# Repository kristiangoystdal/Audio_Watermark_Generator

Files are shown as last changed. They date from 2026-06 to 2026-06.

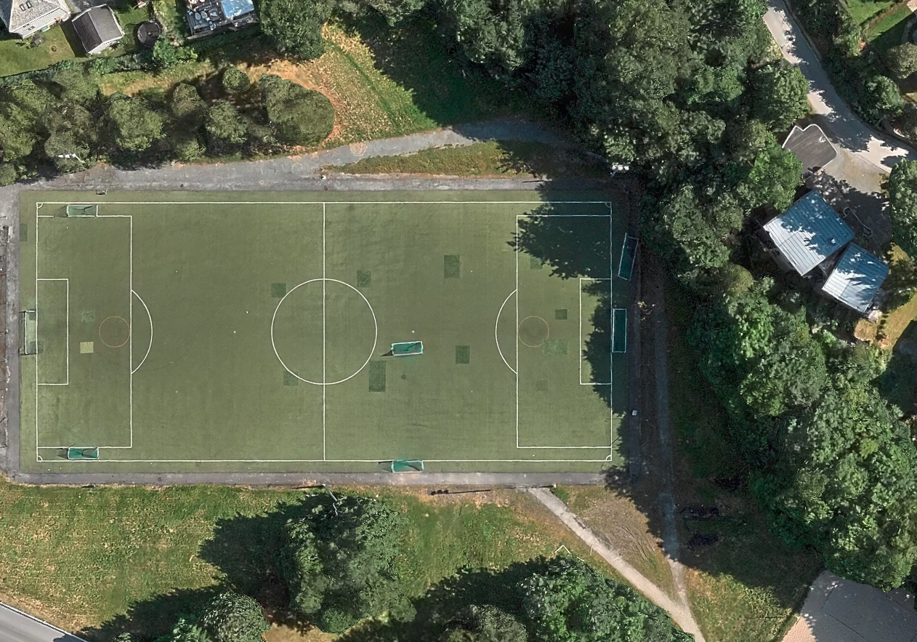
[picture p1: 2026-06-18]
Testing/test_files/acoustic_localization/dødens_dal_2/SATELLITE_IMAGE.png

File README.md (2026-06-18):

# Acoustic Metadata Multiplexer

A low-cost, low-power system for embedding time-synchronized FSK metadata signals into audio recordings made by Autonomous Recording Units (ARUs). Designed for bioacoustic field deployments where cross-unit time synchronization and metadata recovery from audio alone are required.

The system encodes a structured metadata payload as a BFSK signal mixed into the audio recorded by any ARU model — either acoustically via a speaker, or electrically via a 3.5 mm cabled pass-through. A desktop demodulator extracts the metadata from recorded `.wav` files post-deployment.

---

## How It Works

The system operates in a **star topology**: one unit acts as a base station and the others are receivers, one per ARU.

1. **Base station** wakes on a fixed schedule, generates a common payload (message ID, timestamp, user string), and broadcasts it over RF at 433 MHz using the CC1101 transceiver.
2. **Receiver units** listen on the CC1101 in continuous RX mode. On receiving a packet, each receiver generates a BFSK-modulated audio signal encoding the shared payload combined with its own local data (device ID, GPS coordinates, live temperature from DS3231).
3. The FSK signal is mixed into the audio captured by the ARU — either by playing it through a small speaker near the ARU microphone, or by mixing it into a microphone signal over a cabled 3.5 mm connection.
4. Since all receivers embed at the same time (triggered by the same RF packet), the embedded signal appears at the same absolute moment across all ARU recordings — enabling post-hoc time alignment via the message ID.
5. A recorded `.wav` containing the embedded signal can be decoded using the desktop demodulator to recover both the metadata and the synchronization reference point.

**Standalone mode** skips RF communication entirely: the unit generates and embeds its own payload on a fixed schedule, using only locally configured and measured data.

The metadata payload format is:

```
/MID<id>/TIM<timestamp>/STR<string>/DID<device_id>/LOC<lat,lon>/TMP<temperature>/
```

Each field is optional and individually togglable via `user_config.h` or the GUI. `MID` (message ID) is the synchronization anchor — recordings are aligned by matching identical message IDs across units.

---

## Repository Structure

```
Audio_Watermark_Generator/
├── Firmware/                   # STM32G431 embedded firmware
│   ├── Core/
│   │   ├── Inc/                # Headers (drivers, config, DSP)
│   │   └── Src/                # Source (main loop, peripherals, FEC)
│   ├── Drivers/                # HAL, CMSIS, and DSP libraries
│   ├── Middlewares/            # USB device library
│   ├── USB_Device/             # USB CDC interface
│   ├── cmake/                  # CMake toolchain config
│   ├── CMakeLists.txt
│   └── CMakePresets.json
│
├── Hardware/                   # KiCad PCB design
│   ├── *.kicad_sch             # Schematics (MCU, RTC, mixer, speaker, transceiver, battery)
│   ├── *.kicad_pcb             # PCB layout
│   ├── Components/             # Custom footprints, symbols, and 3D models
│   ├── Gerber/                 # Fabrication files
│   └── JCLPCB/                 # BOM and CPL for JLCPCB assembly
│
├── Software/                   # Desktop tools (Python)
│   ├── gui/                    # Configurator and flash tool
│   │   ├── gui.py              # Main GUI application
│   │   ├── build_app.py        # PyInstaller build script
│   │   ├── scripts/            # Config generation, build automation, paths
│   │   └── tools/              # Bundled toolchain (ARM GCC, CMake, Ninja, dfu-util)
│   │
│   └── gui_demodulator/        # Metadata decoder
│       ├── demodulator_gui.py  # Decoder GUI
│       ├── demodulator.py      # FSK demodulation engine
│       └── reed_solomon.py     # Reed-Solomon decoder
│
├── Testing/                    # Test scripts and data
│   ├── scripts/                # Individual test scripts
│   │   └── helper/             # Shared utilities
│   ├── test_files/             # Input audio and measurement data
│   ├── results/                # Output plots and reports
│   └── run_all_tests.py        # Run all tests
│
└── README.md
```

---

## Getting Started

### Prerequisites

| Component | Requirement |
| --- | --- |
| Microcontroller | STM32G431-based board (custom PCB or Nucleo) |
| Toolchain | GNU Arm Embedded Toolchain 13.2+ |
| Build system | CMake + Ninja |
| Programmer | ST-Link V3 or DFU over USB |
| Python | 3.8+ with `tkinter` |

### Install Python Dependencies

```bash
pip install numpy scipy matplotlib soundfile
```

> `tkinter` is included with most Python installations. On Linux, you may need `sudo apt install python3-tk`.

---

## Firmware

### Key Configuration

All metadata and system parameters are defined in [`Firmware/Core/Inc/user_config.h`](Firmware/Core/Inc/user_config.h):

| Parameter | Default | Description |
| --- | --- | --- |
| `USER_STRING` | `"Hello World"` | User-defined string payload |
| `DEVICE_ID` | `42` | Numeric identifier for this unit |
| `LOCATION` | `"63.4190,10.4015"` | GPS coordinates of this ARU |
| `TEMPERATURE` | `20` | Static temperature fallback (overridden by DS3231 reading at runtime) |
| `INCLUDE_USER_STRING` / `INCLUDE_DEVICE_ID` / etc. | `true` | Toggle individual payload fields on/off |
| `FSK_LOWER_FREQUENCY` | `10000` Hz | FSK f0 tone (auto-aligned to DAC sample rate) |
| `FSK_HIGHER_FREQUENCY` | `12000` Hz | FSK f1 tone (auto-aligned to DAC sample rate) |
| `SIGNAL_ATTENUATION` | `100` | Output level (0 = silence, 100 = full) |
| `USE_REED_SOLOMON_ERROR_CORRECTION` | `true` | Enable/disable RS error correction |
| `RS_ERROR_CORRECTION_SYMBOLS` | `20` | Number of RS parity symbols |
| `OPERATION_MODE` | `0` | 0 = Receiver, 1 = Base Station, 2 = Standalone |
| `STARTING_HOUR` / `END_HOUR` | `0` / `23` | Daily schedule window (24h format) |
| `RUN_MINUTES` / `SLEEP_MINUTES` | `3` / `0` | Duty cycle within the schedule window |
| `USE_CABLE_TRANSMISSION` | `false` | Cable (3.5 mm) output instead of speaker |

You can edit this file manually or use the GUI configurator (see below).

### Operation Modes

**Receiver (`OPERATION_MODE=0`)**
Listens on the CC1101 in continuous RX mode. On receiving a packet, the unit generates a metadata string combining shared fields from the RF packet (message ID, timestamp, user string) with its own local fields (device ID, location, temperature), then outputs the BFSK signal. One receiver unit is deployed at each ARU.

**Base Station (`OPERATION_MODE=1`)**
Wakes on a fixed RTC-based schedule, generates a common payload (message ID, RTC timestamp, user string), and transmits it via the CC1101 RF transceiver. One unit per deployment must be configured as the base station.

**Standalone (`OPERATION_MODE=2`)**
No RF communication. The unit wakes on a fixed RTC-based schedule, generates a payload from locally configured and measured values, and outputs the BFSK signal. Used when cross-unit synchronization is not needed.

### Features

- **BFSK metadata embedding** — DMA-driven circular DAC output with pre-computed sine LUTs; frequencies are auto-aligned to integer samples-per-period for zero spectral leakage
- **Reed-Solomon FEC** — GF(2^8) encoder with configurable parity symbols for burst-error-resilient decoding
- **CC1101 sub-GHz RF** — bit-banged SPI driver for 433 MHz base station to receiver synchronization; receiver uses continuous RX mode
- **DS3231 RTC** — I2C temperature-compensated clock with battery backup; software-controlled power gating to save current between reads
- **Scheduled operation** — configurable active hours (`STARTING_HOUR`/`END_HOUR`) and run/sleep duty cycle aligned to AudioMoth duty-cycle timing; RTC wakeup timer for Base Station/Standalone, GPIO interrupt (GDO0) for Receiver (mode 0)
- **Audio output paths** — speaker (GPIO-switched amplifier) or cable (relay-switched gain-neutral mixing mode with op-amp signal chain)
- **Battery monitoring** — ADC reading through a resistor divider; halts with error code if voltage drops below 3.0 V
- **USB CDC** — serial interface for host communication and first-boot RTC time sync
- **Flash-persistent flags** — records whether time sync has been performed (survives power cycles)
- **LED status codes** — 4-bit binary blink patterns encoding error/status codes, repeated 3 times
- **STOP1 low-power mode** — full peripheral suspend between transmissions; clock and I2C re-initialized on wake

### Build

```bash
cd Firmware
cmake -B build/Debug -S . -G Ninja -DCMAKE_BUILD_TYPE=Debug
cmake --build build/Debug
```

### Flash

**Via ST-Link:**

```bash
openocd -f interface/stlink.cfg -f target/stm32g4x.cfg \
  -c "program build/Debug/Audio_Watermark_Generator.elf verify reset exit"
```

**Via DFU (USB):**
The GUI flash tool handles DFU flashing automatically. Alternatively, use `dfu-util` directly.

---

## Software Tools

### Configurator & Flash Tool

A desktop GUI for configuring metadata parameters and flashing the firmware to the STM32.

```bash
cd Software/gui
python3 gui.py
```

**What it does:**

- Configure metadata fields per operation mode (base station, receiver, standalone)
- Set FSK frequencies, attenuation, and Reed-Solomon error correction
- Set operation schedule (active hours, run/sleep intervals)
- Generate `user_config.h`, build the firmware, and flash over DFU

The tool bundles its own ARM toolchain, CMake, Ninja, and dfu-util in `Software/gui/tools/`, so no manual toolchain setup is needed when using the GUI.

### Metadata Decoder

A desktop GUI for extracting embedded metadata from recorded audio files.

```bash
cd Software/gui_demodulator
python3 demodulator_gui.py
```

**What it does:**

- Load a `.wav` recording containing an embedded BFSK signal
- Perform FSK demodulation and Reed-Solomon decoding
- Display the decoded metadata payload
- Visualize the demodulated spectrum and signal

### Pre-built macOS Apps

Beta `.app` builds are available for macOS:

- **Audio Watermark Flash Tool** — configure and flash
- **FSK Audio Demodulator** — decode metadata from recordings

[Download the latest release](../../releases/latest)

---

## Testing

The `Testing/` directory contains scripts for characterizing and validating system performance.

### Test Scripts

| Script | Description |
| --- | --- |
| `autotest.py` | Automated demodulator correctness testing |
| `drift.py` | Frequency drift measurement over time |
| `ecc_burst_test.py` | Reed-Solomon burst error correction validation |
| `offset_calculation.py` | Timing offset between devices |
| `localize.py` | Acoustic localization from multi-receiver recordings |
| `localize_tdoa.py` | Time-difference-of-arrival (TDOA) localization |
| `audio_passthrough.py` | Audio signal chain validation (FFT analysis) |
| `spec_leak.py` | Spectral purity and leakage analysis |
| `timing.py` | Transmission timing validation |
| `wakeup.py` | Sleep/wakeup mechanism testing |
| `plot_fsk_signals.py` | FSK signal visualization |
| `plot_bird_spectrograms.py` | Spectrogram analysis of bird audio |
| `plot_current.py` | Current consumption analysis |
| `plot_rssi.py` | RF signal strength plotting |
| `plot_temperature.py` | Temperature variation analysis |

### Test Data

Test input data is organized in `Testing/test_files/`:

- `demodulator_autotest/` — Pre-recorded samples for demodulator validation
- `acoustic_localization/` — Multi-receiver recordings for TDOA testing
- `rtc_measurements/` — RTC drift data
- `range_tests/` — Distance-dependent RF signal quality
- `current_measures/` — Power consumption logs
- `temperature_range/` — Temperature sweep recordings

### Run All Tests

```bash
cd Testing
python3 run_all_tests.py
```

---

## Hardware

The custom 4-layer PCB is designed in KiCad and includes:

- **STM32G431** microcontroller
- **DS3231** RTC with battery backup
- **CC1101** RF transceiver (433 MHz, sub-GHz)
- Audio mixer with gain-neutral pass-through and speaker driver
- USB connector
- Battery power management

Design files are in `Hardware/`:

- Schematics: individual `.kicad_sch` files for each subsystem
- PCB layout: `Audio_watermark_generator.kicad_pcb`
- 3D model: `Audio_watermark_generator.step`
- Fabrication: `Gerber/` directory with Gerber + drill files
- Assembly: `JCLPCB/` with BOM and CPL for JLCPCB ordering
- Custom components: `Components/` with footprints, symbols, and 3D models

---

## Contributing

1. Fork the repository
2. Create a feature branch (`git checkout -b feature/my-feature`)
3. Commit your changes
4. Push and open a pull request

---

## Contributors

- **Kristian Gøystdal** — Developer
- **Einar Bergslid** — Developer

---

## License

Released under the **MIT License**. Free to use, modify, and distribute.

---

`stm32` · `bioacoustics` · `autonomous-recording-unit` · `time-synchronization` · `fsk` · `metadata-embedding` · `reed-solomon` · `kicad` · `python`

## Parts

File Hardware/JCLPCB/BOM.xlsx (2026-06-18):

Reference | Qty | Value | DNP | Footprint | LCSC Part #
 |  |  | DNP
C1 | 1 | 4u7F |  | Capacitor_SMD:C_0603_1608Metric | C19666
C2,C3,C9,C20,C51 | 5 | 100nF |  | Capacitor_SMD:C_0402_1005Metric | C1525
C4,C21,C22 | 3 | 10nF |  | Capacitor_SMD:C_0402_1005Metric | C15195
C5,C6,C15 | 3 | 1uF |  | Capacitor_SMD:C_0603_1608Metric | C15849
C7,C8 | 2 | 10pF |  | Capacitor_SMD:C_0402_1005Metric | C32949
C10,C11 | 2 | 22uF |  | Capacitor_SMD:C_0805_2012Metric | C45783
C12,C16 | 2 | 10uF |  | Capacitor_SMD:C_0805_2012Metric | C440198
C13,C14 | 2 | 4n7F |  | Capacitor_SMD:C_0603_1608Metric | C53987
C17,C18,C23,C24,C25,C124,C125 | 7 | 220pF |  | Capacitor_SMD:C_0402_1005Metric | C71693
C19 | 1 | 1uF |  | Capacitor_SMD:C_0805_2012Metric | C77079
C26,C27,C28 | 3 | 22uF |  | Capacitor_SMD:C_0603_1608Metric | C84419
C81 | 1 | 12pF |  | Capacitor_SMD:C_0402_1005Metric | C1547
C101 | 1 | 15pF |  | Capacitor_SMD:C_0402_1005Metric | C1548
C121,C131 | 2 | 3p9F |  | Capacitor_SMD:C_0402_1005Metric | C85940
C122 | 1 | 8p2F |  | Capacitor_SMD:C_0402_1005Metric | C76984
C123 | 1 | 5p6F |  | Capacitor_SMD:C_0402_1005Metric | C85941
D1 | 1 | RED |  | LED_SMD:LED_0603_1608Metric | C2286
FB1 | 1 | 120R |  | Inductor_SMD:L_0603_1608Metric | C14709
FB2,FB3 | 2 | 600R |  | Inductor_SMD:L_0603_1608Metric | C1002
FB4 | 1 | 1kR |  | Inductor_SMD:L_0402_1005Metric | C76889
IC1 | 1 | STM32G431KBT6 (https://www.digikey.com/en/products/detail/stmicroelectronics/STM32G431KBT6/10231564) |  | QFP80P900X900X160-32N | C529357
IC2 | 1 | ISL91107IRTNZ-T7A (https://no.rs-online.com/web/p/voltage-regulators/1230989) |  | QFN50P300X400X80-21N | C2071659
J1 | 1 | USB_B_Micro (https://no.rs-online.com/web/p/usb-connectors/1225099) |  | USB_Micro-B_Wuerth_629105150521 | C2894326
 |  |  | DNP
 |  |  | DNP
J4,J5 | 2 | SJ2-35954A-SMT-TR |  | CUI_SJ2-35954A-SMT-TR | C4992345
J6 | 1 | 533980271_Picoblade (https://no.rs-online.com/web/p/pcb-headers/6563024) |  | MOLEX_533980271_Picoblade | C122410
 |  |  | DNP
 |  |  | DNP
K1 | 1 | AGQ210S03 (https://www.digikey.no/no/products/detail/panasonic-electric-works/AGQ210S03/644869) |  | AGQ210S03 | C5582831
L1 | 1 | 1uH |  | Inductor_SMD:L_1008_2520Metric | C470857
L121,L123,L131 | 3 | 27nH |  | Inductor_SMD:L_0402_1005Metric | C12669
L122 | 1 | 22nH |  | Inductor_SMD:L_0402_1005Metric | C12670
R1 | 1 | 1k5R |  | Resistor_SMD:R_0402_1005Metric | C25867
R2 | 1 | 10kR |  | Resistor_SMD:R_0402_1005Metric | C25744
R3,R4,R5,R6 | 4 | 100kR |  | Resistor_SMD:R_0805_2012Metric | C25611
R7 | 1 | 2kR |  | Resistor_SMD:R_0805_2012Metric | C17604
R8,R9 | 2 | 10kR |  | Resistor_SMD:R_0805_2012Metric | C17414
R10,R12 | 2 | 1kR |  | Resistor_SMD:R_0805_2012Metric | C17513
R11 | 1 | 1MR |  | Resistor_SMD:R_0805_2012Metric | C17514
R13,R14 | 2 | 330kR |  | Resistor_SMD:R_0805_2012Metric | C17629
R171 | 1 | 56kR |  | Resistor_SMD:R_0402_1005Metric | C71703
SW2,SW1 | 2 | SW_SPDT (https://no.rs-online.com/web/p/slide-switches/7931721) |  | SW_SPDT_PCM12 | C221841
U1 | 1 | AMS1117-3.3 (https://www.digikey.no/no/products/detail/umw/AMS1117-3-3/17635254) |  | Package_TO_SOT_SMD:SOT-223-3_TabPin2 | C6186
U2 | 1 | L9110S |  | Driver:SOIC127P599X172-8N | C725793
U3,U4 | 2 | MCP6072 (https://www.digikey.no/no/products/detail/microchip-technology/MCP6072-E-SN/2059969) |  | OpAmp:SOIC127P599X175-8N | C122875
U5 | 1 | PAM8304 (https://no.farnell.com/diodes-inc/pam8304asr/audio-power-amp-d-40-to-85deg/dp/3373822) |  | Audio_Module:PAM8304ASR | C581342
 |  |  | DNP
U8 | 1 | CC1101 (https://no.rs-online.com/web/p/rf-ics/8203068) |  | RF_Module:CC1101 | C29953
Y1 | 1 | 16MHz (https://no.rs-online.com/web/p/crystal-units/2365070) |  | Crystal:Crystal_SMD_3225-4Pin_3.2x2.5mm | C112972
Y2 | 1 | 26Mhz (https://no.rs-online.com/web/p/crystal-units/2365070) |  | Crystal:Crystal_SMD_3225-4Pin_3.2x2.5mm | C485372

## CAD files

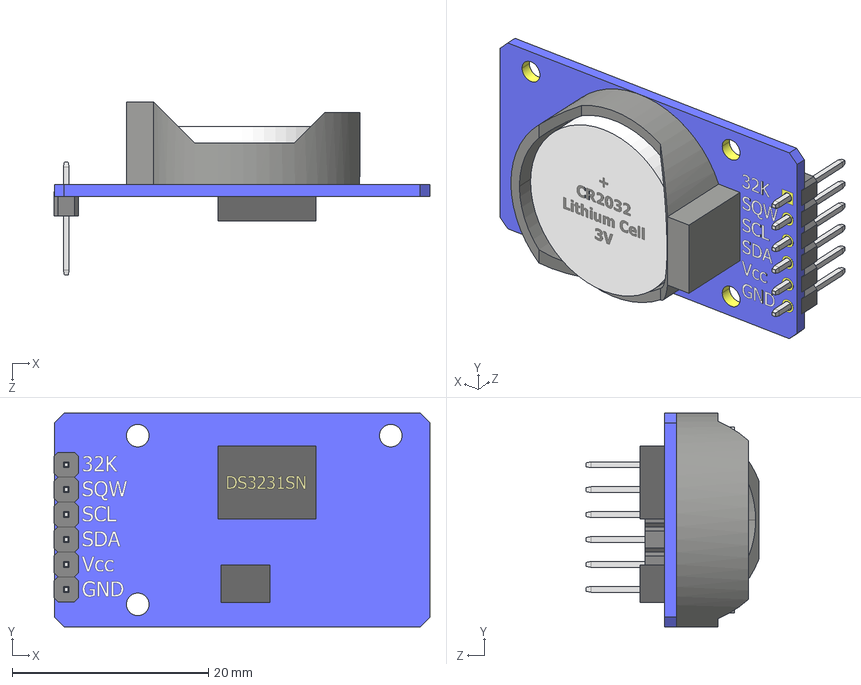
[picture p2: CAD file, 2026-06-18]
Hardware/Components/Models/DS3231 Timer Assembly.STEP
38.3 x 21.8 x 17.6 mm
PCB Timer
Battery Holder
ICs
HEADER10P

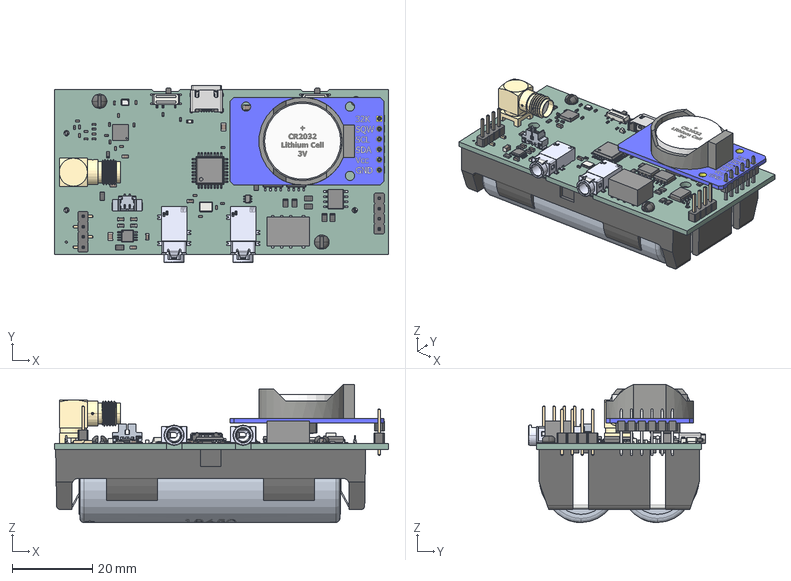
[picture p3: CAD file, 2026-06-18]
Hardware/Audio_watermark_generator.step
83.0 x 44.1 x 34.3 mm
C_0402_1005Metric x 21
PinHeader_1x04_P2.54mm_Vertical_SMD_Pin1Right
ThermalPin
PinsArrayLR x 3
PinsArrayTB x 2
C_0805_2012Metric x 7
C_0603_1608Metric x 9
PCB Timer
Battery Holder
ICs
HEADER10P
Crystal_SMD_3225-4Pin_3.2x2.5mm
L_0603_1608Metric x 3
CC1101
logo
dot
pins
R_0805_2012Metric x 16
CONSMA002-SMD-G-T
L_0402_1005Metric x 4
LED_0603_1608Metric
MCP6072-E_SN x 3
R_0603_1608Metric
SJ2-35954A-SMT-TR--3DModel-STEP-1 x 2
R_0402_1005Metric x 2
PAM8304ASR
629105150521_Housing
629105150521_Pin1 x 4
629105150521_Pin2
629105150521_Shielding2
629105150521_Shielding
L_1210_3225Metric
PinHeader_1x04_P2.54mm_Vertical
Pins
SOT-223
SW_SPDT_PCM12 x 2
keystone-PN1049
Audio_watermark_generator_PCB

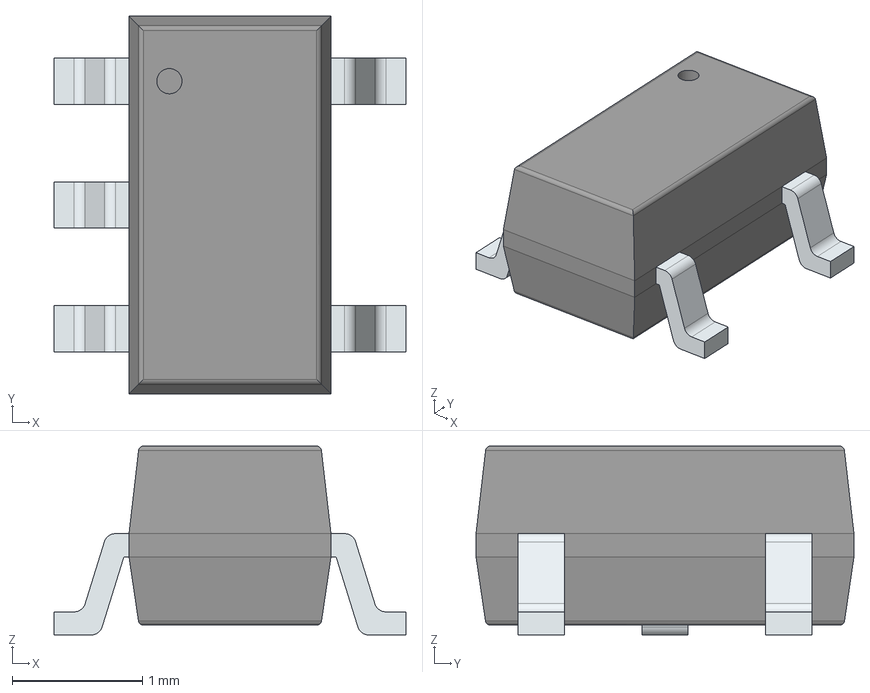
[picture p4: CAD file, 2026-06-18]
Hardware/Components/Models/MCP6071T-E_OT.stp
2.70 x 2.90 x 1.45 mm
PinsArrayL
PinsArrayR

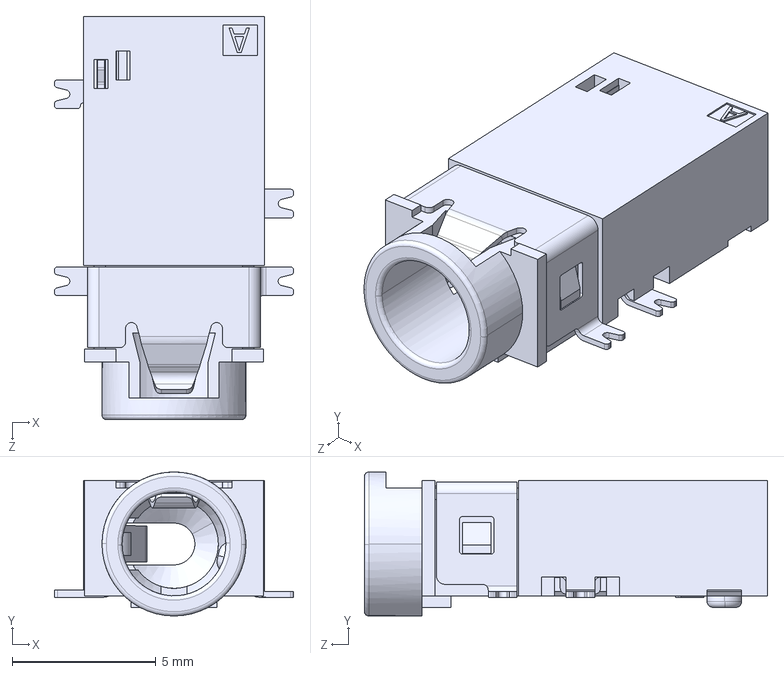
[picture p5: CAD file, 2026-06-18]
Hardware/Components/Models/SJ2-35954A-SMT-TR--3DModel-STEP-1.STEP
8.30 x 5.00 x 14.0 mm

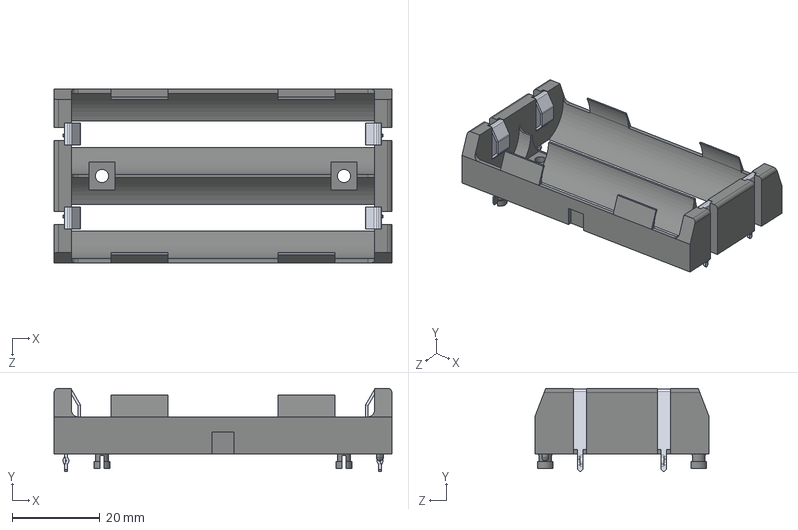
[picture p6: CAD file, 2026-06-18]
Hardware/Components/Models/1049.stp
77.1 x 19.0 x 39.8 mm

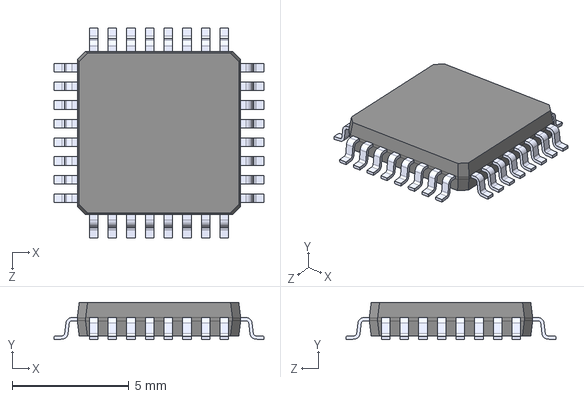
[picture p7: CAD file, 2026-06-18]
Hardware/Components/Models/STM32G431KBT6.STEP
9.00 x 1.60 x 9.00 mm

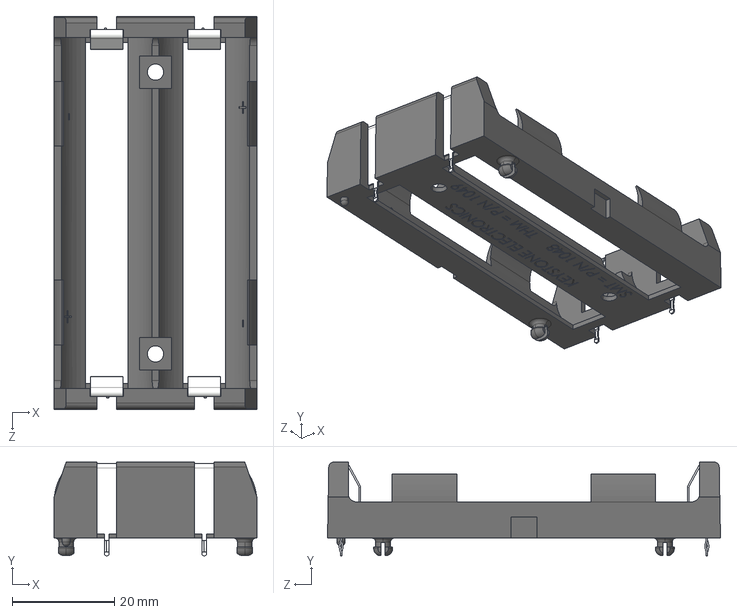
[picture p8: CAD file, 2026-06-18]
Hardware/Components/Models/keystone-PN1049.STEP
39.8 x 18.4 x 77.1 mm

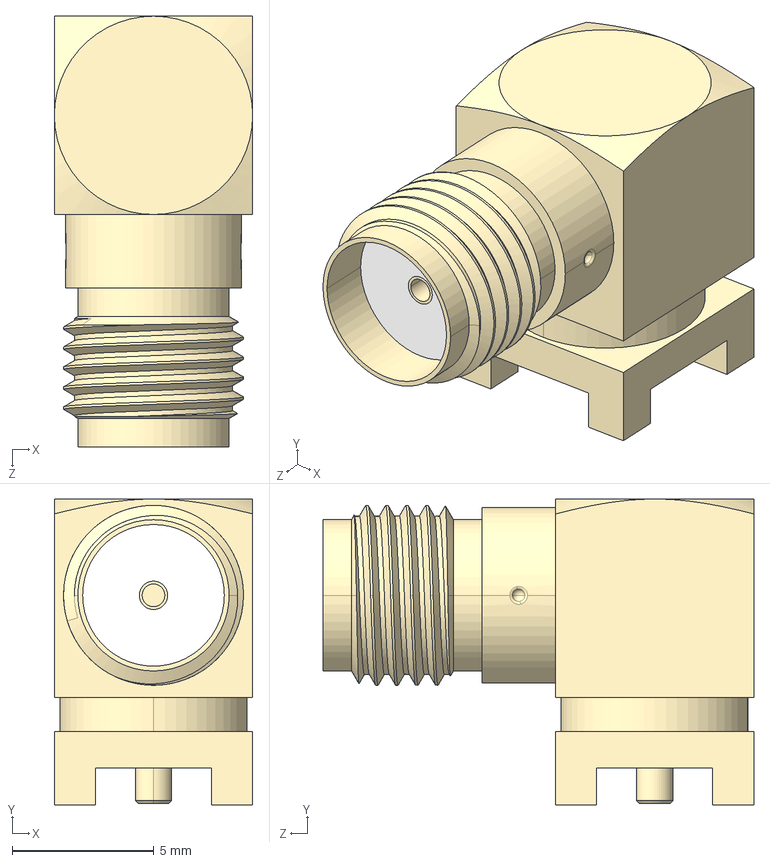
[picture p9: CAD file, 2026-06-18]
Hardware/Components/Models/CONSMA002-SMD-G-T.step
7.00 x 10.8 x 15.2 mm

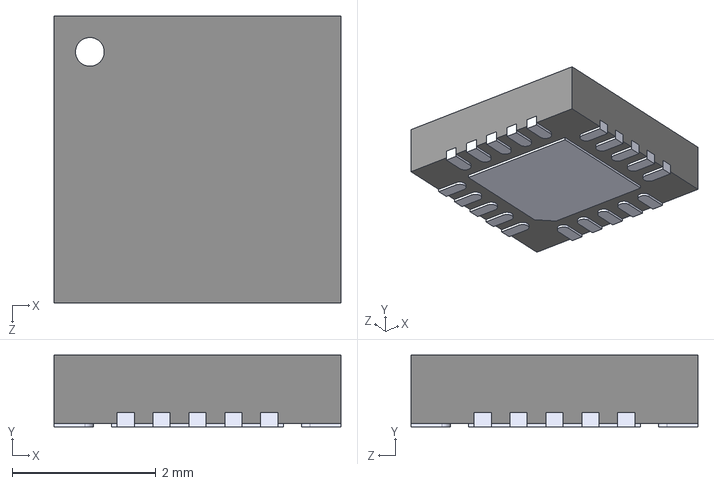
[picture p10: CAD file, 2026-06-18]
Hardware/Components/Models/CC1101.step
4.00 x 1.00 x 4.00 mm

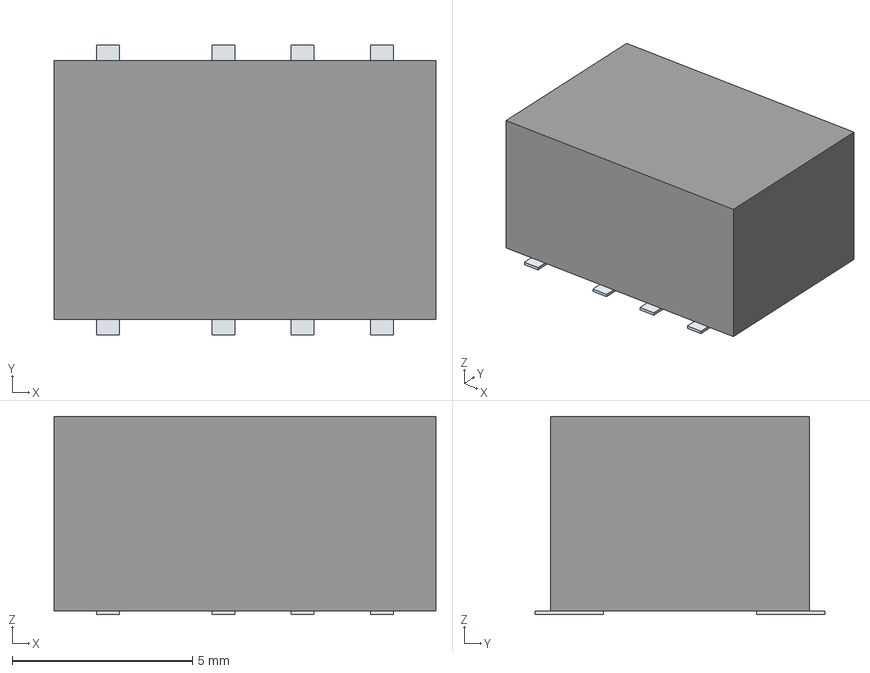
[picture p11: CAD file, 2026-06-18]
Hardware/Components/Models/AGQ210S03.stp
10.6 x 8.04 x 5.50 mm
Pins

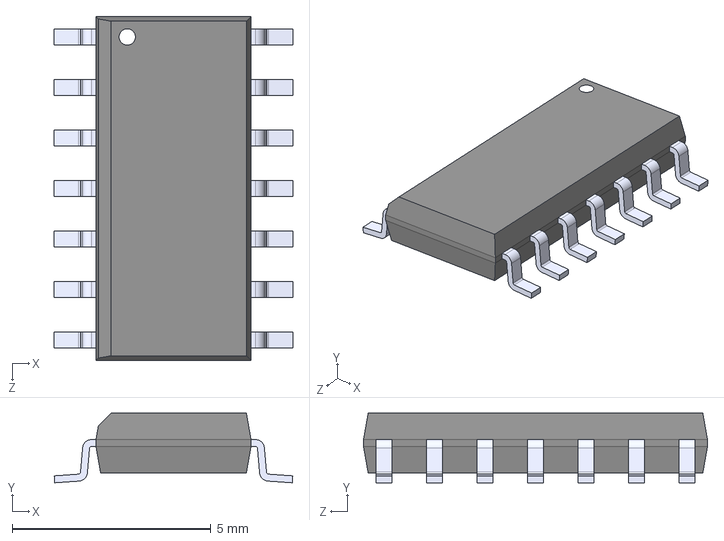
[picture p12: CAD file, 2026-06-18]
Hardware/Components/Models/MCP6004-I_SL.STEP
6.00 x 1.75 x 8.65 mm

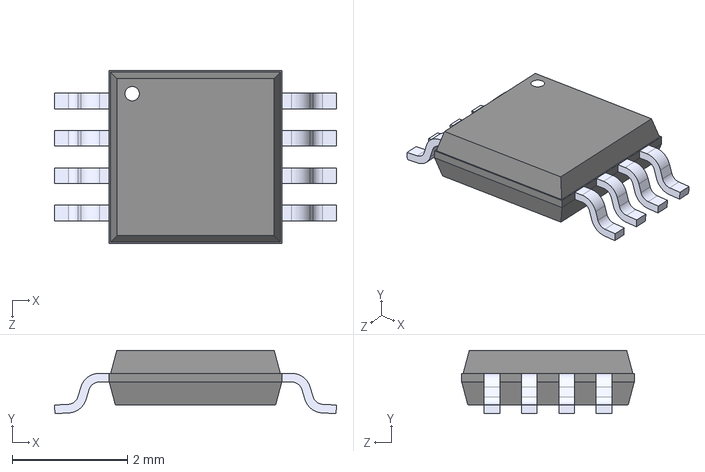
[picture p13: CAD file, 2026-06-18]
Hardware/Components/Models/PAM8304ASR.step
4.90 x 1.10 x 3.00 mm

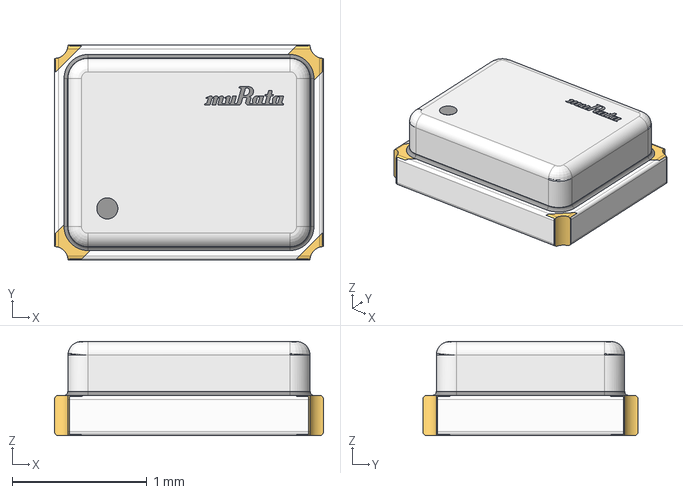
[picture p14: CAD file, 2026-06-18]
Hardware/Components/Models/XRCGB26M000F1S1DR0.stp
2.00 x 1.60 x 0.702 mm

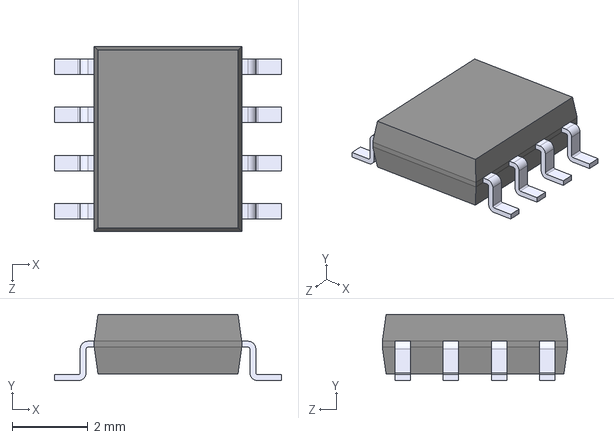
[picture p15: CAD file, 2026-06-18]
Hardware/Components/Models/MCP6072-E_SN.step
6.00 x 1.75 x 4.90 mm

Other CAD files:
Hardware/Components/Models/AGQ200S03Z.stp
Hardware/Components/Models/STG3157CTR.stp
Hardware/Components/Models/L9110S--3DModel-STEP-269445.STEP
Hardware/Components/Models/18650.STEP
Hardware/Components/Models/533980271.step
Hardware/Components/Models/629105150521+%28rev1%29.stp
Hardware/Components/Models/ISL91107IRTNZ-T7A.stp
Hardware/Components/Models/MCP6004-I_P.STEP

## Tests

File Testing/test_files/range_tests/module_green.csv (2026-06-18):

Distance (m) | Module | RX Data | RSSI (dBm)
5 | green | *ë/MID00/STRHello World/TIM1211500522052026 | -57
5 | green | *ë/MID00/STRHello World/TIM1211560522052026 | -56
5 | green | *ë/MID00/STRHello World/TIM1212030522052026 | -55
5 | green | *ë/MID00/STRHello World/TIM1212100522052026 | -56
5 | green | *ë/MID00/STRHello World/TIM1212190522052026 | -54
5 | green | *ë/MID00/STRHello World/TIM1212250522052026 | -52
5 | green | *ë/MID00/STRHello World/TIM1212320522052026 | -52
5 | green | *ë/MID00/STRHello World/TIM1212390522052026 | -51
5 | green | *ë/MID00/STRHello World/TIM1212490522052026 | -50
5 | green | *ë/MID00/STRHello World/TIM1212580522052026 | -50
10 | green | *ë/MID00/STRHello World/TIM1226410522052026 | -61
10 | green | *ë/MID00/STRHello World/TIM1226470522052026 | -60
10 | green | *ë/MID00/STRHello World/TIM1226540522052026 | -61
10 | green | *ë/MID00/STRHello World/TIM1227010522052026 | -62
10 | green | *ë/MID00/STRHello World/TIM1227080522052026 | -62
10 | green | *ë/MID00/STRHello World/TIM1227140522052026 | -62
10 | green | *ë/MID00/STRHello World/TIM1227210522052026 | -63
10 | green | *ë/MID00/STRHello World/TIM1227270522052026 | -63
10 | green | *ë/MID00/STRHello World/TIM1227340522052026 | -63
10 | green | *ë/MID00/STRHello World/TIM1227480522052026 | -61
10 | green | *ë/MID00/STRHello World/TIM1227540522052026 | -61
15 | green | *ë/MID00/STRHello World/TIM1229080522052026 | -61
15 | green | *ë/MID00/STRHello World/TIM1229140522052026 | -62
15 | green | *ë/MID00/STRHello World/TIM1229210522052026 | -62
15 | green | *ë/MID00/STRHello World/TIM1229330522052026 | -61
15 | green | *ë/MID00/STRHello World/TIM1229400522052026 | -62
15 | green | *ë/MID00/STRHello World/TIM1229470522052026 | -62
15 | green | *ë/MID00/STRHello World/TIM1229540522052026 | -62
15 | green | *ë/MID00/STRHello World/TIM1230010522052026 | -62
15 | green | *ë/MID00/STRHello World/TIM1230070522052026 | -63
15 | green | *ë/MID00/STRHello World/TIM1230140522052026 | -63
15 | green | *ë/MID00/STRHello World/TIM1230210522052026 | -62
20 | green | *ë/MID00/STRHello World/TIM1231460522052026 | -64
20 | green | *ë/MID00/STRHello World/TIM1231530522052026 | -64
20 | green | *ë/MID00/STRHello World/TIM1232000522052026 | -64
20 | green | *ë/MID00/STRHello World/TIM1232070522052026 | -64
20 | green | *ë/MID00/STRHello World/TIM1232130522052026 | -64
20 | green | *ë/MID00/STRHello World/TIM1232200522052026 | -64
20 | green | *ë/MID00/STRHello World/TIM1232270522052026 | -64
20 | green | *ë/MID00/STRHello World/TIM1232340522052026 | -64
20 | green | *ë/MID00/STRHello World/TIM1232400522052026 | -64
20 | green | *ë/MID00/STRHello World/TIM1232470522052026 | -65
25 | green | *ë/MID00/STRHello World/TIM1233470522052026 | -67
25 | green | *ë/MID00/STRHello World/TIM1233540522052026 | -65
25 | green | *ë/MID00/STRHello World/TIM1234010522052026 | -67
25 | green | *ë/MID00/STRHello World/TIM1234070522052026 | -66
25 | green | *ë/MID00/STRHello World/TIM1234140522052026 | -67
25 | green | *ë/MID00/STRHello World/TIM1234220522052026 | -66
25 | green | *ë/MID00/STRHello World/TIM1234280522052026 | -66
25 | green | *ë/MID00/STRHello World/TIM1234350522052026 | -66
25 | green | *ë/MID00/STRHello World/TIM1234420522052026 | -66
25 | green | *ë/MID00/STRHello World/TIM1234490522052026 | -65
30 | green | *ë/MID00/STRHello World/TIM1235390522052026 | -69
30 | green | *ë/MID00/STRHello World/TIM1235460522052026 | -69
30 | green | *ë/MID00/STRHello World/TIM1235530522052026 | -69
30 | green | *ë/MID00/STRHello World/TIM1236000522052026 | -70
30 | green | *ë/MID00/STRHello World/TIM1236070522052026 | -70
30 | green | *ë/MID00/STRHello World/TIM1236140522052026 | -70
30 | green | *ë/MID00/STRHello World/TIM1236210522052026 | -73
30 | green | *ë/MID00/STRHello World/TIM1236280522052026 | -73
30 | green | *ë/MID00/STRHello World/TIM1236340522052026 | -74
30 | green | *ë/MID00/STRHello World/TIM1236410522052026 | -73
35 | green | *ë/MID00/STRHello World/TIM1237320522052026 | -76
35 | green | *ë/MID00/STRHello World/TIM1237390522052026 | -77
35 | green | *ë/MID00/STRHello World/TIM1237460522052026 | -76
35 | green | *ë/MID00/STRHello World/TIM1237520522052026 | -77
35 | green | *ë/MID00/STRHello World/TIM1237590522052026 | -73
35 | green | *ë/MID00/STRHello World/TIM1238060522052026 | -71
35 | green | *ë/MID00/STRHello World/TIM1238130522052026 | -70
35 | green | *ë/MID00/STRHello World/TIM1238200522052026 | -69
35 | green | *ë/MID00/STRHello World/TIM1238270522052026 | -69
35 | green | *ë/MID00/STRHello World/TIM1238350522052026 | -70
40 | green | *ë/MID00/STRHello World/TIM1239270522052026 | -74
40 | green | *ë/MID00/STRHello World/TIM1239340522052026 | -73
40 | green | *ë/MID00/STRHello World/TIM1239400522052026 | -73
40 | green | *ë/MID00/STRHello World/TIM1239470522052026 | -74
40 | green | *ë/MID00/STRHello World/TIM1239540522052026 | -73
40 | green | *ë/MID00/STRHello World/TIM1240010522052026 | -73
40 | green | *ë/MID00/STRHello World/TIM1240070522052026 | -74
40 | green | *ë/MID00/STRHello World/TIM1240140522052026 | -71
40 | green | *ë/MID00/STRHello World/TIM1240210522052026 | -71
40 | green | *ë/MID00/STRHello World/TIM1240270522052026 | -70
45 | green | *ë/MID00/STRHello World/TIM1312160522052026 | -87
45 | green | *ë/MID01/STRHello World/TIM1312190522052026 | -84
45 | green | *ë/MID02/STRHello World/TIM1312220522052026 | -83
45 | green | *ë/MID03/STRHello World/TIM1312250522052026 | -85
45 | green | *ë/MID04/STRHello World/TIM1312280522052026 | -84
45 | green | *ë/MID05/STRHello World/TIM1312310522052026 | -88
45 | green | *ë/MID06/STRHello World/TIM1312340522052026 | -86
45 | green | *ë/MID07/STRHello World/TIM1312380522052026 | -86
45 | green | *ë/MID08/STRHello World/TIM1312410522052026 | -87
45 | green | *ë/MID09/STRHello World/TIM1312440522052026 | -89
50 | green | *ë/MID00/STRHello World/TIM1313290522052026 | -82
50 | green | *ë/MID01/STRHello World/TIM1313330522052026 | -81
50 | green | *ë/MID02/STRHello World/TIM1313360522052026 | -81
50 | green | *ë/MID03/STRHello World/TIM1313390522052026 | -80
50 | green | *ë/MID04/STRHello World/TIM1313420522052026 | -82
50 | green | *ë/MID05/STRHello World/TIM1313450522052026 | -81
50 | green | *ë/MID06/STRHello World/TIM1313480522052026 | -80
50 | green | *ë/MID07/STRHello World/TIM1313510522052026 | -81
50 | green | *ë/MID08/STRHello World/TIM1313540522052026 | -79
50 | green | *ë/MID09/STRHello World/TIM1313570522052026 | -80
55 | green | *ë/MID00/STRHello World/TIM1314490522052026 | -80
55 | green | *ë/MID01/STRHello World/TIM1314520522052026 | -78
55 | green | *ë/MID02/STRHello World/TIM1314550522052026 | -77
55 | green | *ë/MID03/STRHello World/TIM1314590522052026 | -78
55 | green | *ë/MID04/STRHello World/TIM1315020522052026 | -77
55 | green | *ë/MID05/STRHello World/TIM1315050522052026 | -78
55 | green | *ë/MID06/STRHello World/TIM1315080522052026 | -74
55 | green | *ë/MID07/STRHello World/TIM1315110522052026 | -70
55 | green | *ë/MID08/STRHello World/TIM1315140522052026 | -70
55 | green | *ë/MID09/STRHello World/TIM1315170522052026 | -72
60 | green | *ë/MID00/STRHello World/TIM1316020522052026 | -86
60 | green | *ë/MID01/STRHello World/TIM1316050522052026 | -83
60 | green | *ë/MID02/STRHello World/TIM1316080522052026 | -85
60 | green | *ë/MID03/STRHello World/TIM1316110522052026 | -84
60 | green | *ë/MID04/STRHello World/TIM1316140522052026 | -85
60 | green | *ë/MID05/STRHello World/TIM1316170522052026 | -83
60 | green | *ë/MID06/STRHello World/TIM1316200522052026 | -81
60 | green | *ë/MID07/STRHello World/TIM1316230522052026 | -84
60 | green | *ë/MID08/STRHello World/TIM1316260522052026 | -83
60 | green | *ë/MID09/STRHello World/TIM1316300522052026 | -82
65 | green | *ë/MID01/STRHello World/TIM1317140522052026 | -94
65 | green | *ë/MID02/STRHello World/TIM1317170522052026 | -86
65 | green | *ë/MID03/STRHello World/TIM1317200522052026 | -86
65 | green | *ë/MID04/STRHello World/TIM1317240522052026 | -83
65 | green | *ë/MID05/STRHello World/TIM1317270522052026 | -88
65 | green | *ë/MID06/STRHello World/TIM1317300522052026 | -89
65 | green | *ë/MID07/STRHello World/TIM1317330522052026 | -85
65 | green | *ë/MID08/STRHello World/TIM1317360522052026 | -85
65 | green | *ë/MID09/STRHello World/TIM1317390522052026 | -89
70 | green | *ë/MID00/STRHello World/TIM1318290522052026 | -83
70 | green | *ë/MID01/STRHello World/TIM1318320522052026 | -83
70 | green | *ë/MID02/STRHello World/TIM1318350522052026 | -82
70 | green | *ë/MID03/STRHello World/TIM1318380522052026 | -84
70 | green | *ë/MID04/STRHello World/TIM1318410522052026 | -83
70 | green | *ë/MID05/STRHello World/TIM1318440522052026 | -83
70 | green | *ë/MID06/STRHello World/TIM1318470522052026 | -82
70 | green | *ë/MID07/STRHello World/TIM1318500522052026 | -84
70 | green | *ë/MID08/STRHello World/TIM1318540522052026 | -85
70 | green | *ë/MID09/STRHello World/TIM1318570522052026 | -85
75 | green | *ë/MID00/STRHello World/TIM1334300522052026 | -78
75 | green | *ë/MID01/STRHello World/TIM1334330522052026 | -78
75 | green | *ë/MID02/STRHello World/TIM1334360522052026 | -78
75 | green | *ë/MID03/STRHello World/TIM1334400522052026 | -77
75 | green | *ë/MID04/STRHello World/TIM1334430522052026 | -76
75 | green | *ë/MID05/STRHello World/TIM1334460522052026 | -77
75 | green | *ë/MID06/STRHello World/TIM1334490522052026 | -76
75 | green | *ë/MID07/STRHello World/TIM1334520522052026 | -75
75 | green | *ë/MID08/STRHello World/TIM1334550522052026 | -76
75 | green | *ë/MID09/STRHello World/TIM1334580522052026 | -75
80 | green | *ë/MID01/STRHello World/TIM1335520522052026 | -92
80 | green | *ë/MID03/STRHello World/TIM1335580522052026 | -92
80 | green | *ë/MID04/STRHello World/TIM1336010522052026 | -88
80 | green | *ë/MID05/STRHello World/TIM1336040522052026 | -85
80 | green | *ë/MID06/STRHello World/TIM1336070522052026 | -84
80 | green | *ë/MID07/STRHello World/TIM1336100522052026 | -83
80 | green | *ë/MID08/STRHello World/TIM1336140522052026 | -85
80 | green | *ë/MID09/STRHello World/TIM1336170522052026 | -84
85 | green | *ë/MID00/STRHello World/TIM1339050522052026 | -80
85 | green | *ë/MID01/STRHello World/TIM1339080522052026 | -79
85 | green | *ë/MID02/STRHello World/TIM1339110522052026 | -78
85 | green | *ë/MID03/STRHello World/TIM1339140522052026 | -80
85 | green | *ë/MID04/STRHello World/TIM1339180522052026 | -81
85 | green | *ë/MID05/STRHello World/TIM1339210522052026 | -79
85 | green | *ë/MID06/STRHello World/TIM1339240522052026 | -79
85 | green | *ë/MID07/STRHello World/TIM1339270522052026 | -78
85 | green | *ë/MID08/STRHello World/TIM1339300522052026 | -78
85 | green | *ë/MID09/STRHello World/TIM1339330522052026 | -79
90 | green | *ë/MID00/STRHello World/TIM1340400522052026 | -78
90 | green | *ë/MID01/STRHello World/TIM1340430522052026 | -82
90 | green | *ë/MID02/STRHello World/TIM1340470522052026 | -79
90 | green | *ë/MID03/STRHello World/TIM1340500522052026 | -80
90 | green | *ë/MID04/STRHello World/TIM1340530522052026 | -81
90 | green | *ë/MID05/STRHello World/TIM1340560522052026 | -79
90 | green | *ë/MID06/STRHello World/TIM1340590522052026 | -80
90 | green | *ë/MID07/STRHello World/TIM1341020522052026 | -79
90 | green | *ë/MID08/STRHello World/TIM1341050522052026 | -77
90 | green | *ë/MID09/STRHello World/TIM1341080522052026 | -80
95 | green | *ë/MID00/STRHello World/TIM1342480522052026 | -77
95 | green | *ë/MID01/STRHello World/TIM1342510522052026 | -79
95 | green | *ë/MID02/STRHello World/TIM1342540522052026 | -76
95 | green | *ë/MID03/STRHello World/TIM1342570522052026 | -78
95 | green | *ë/MID04/STRHello World/TIM1343000522052026 | -78
95 | green | *ë/MID05/STRHello World/TIM1343040522052026 | -77
95 | green | *ë/MID06/STRHello World/TIM1343070522052026 | -78
95 | green | *ë/MID07/STRHello World/TIM1343100522052026 | -77
95 | green | *ë/MID08/STRHello World/TIM1343130522052026 | -79
95 | green | *ë/MID09/STRHello World/TIM1343160522052026 | -78
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

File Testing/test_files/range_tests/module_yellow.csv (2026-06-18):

Distance (m) | Module | RX Data | RSSI (dBm)
5 | yellow | *ë/MID00/STRHello World/TIM1211500522052026 | -52
5 | yellow | *ë/MID00/STRHello World/TIM1211560522052026 | -49
5 | yellow | *ë/MID00/STRHello World/TIM1212030522052026 | -49
5 | yellow | *ë/MID00/STRHello World/TIM1212100522052026 | -49
5 | yellow | *ë/MID00/STRHello World/TIM1212190522052026 | -48
5 | yellow | *ë/MID00/STRHello World/TIM1212250522052026 | -49
5 | yellow | *ë/MID00/STRHello World/TIM1212320522052026 | -48
5 | yellow | *ë/MID00/STRHello World/TIM1212390522052026 | -49
5 | yellow | *ë/MID00/STRHello World/TIM1212490522052026 | -47
5 | yellow | *ë/MID00/STRHello World/TIM1212580522052026 | -46
10 | yellow | *ë/MID00/STRHello World/TIM1226410522052026 | -54
10 | yellow | *ë/MID00/STRHello World/TIM1226470522052026 | -54
10 | yellow | *ë/MID00/STRHello World/TIM1226540522052026 | -55
10 | yellow | *ë/MID00/STRHello World/TIM1227010522052026 | -56
10 | yellow | *ë/MID00/STRHello World/TIM1227080522052026 | -54
10 | yellow | *ë/MID00/STRHello World/TIM1227140522052026 | -55
10 | yellow | *ë/MID00/STRHello World/TIM1227210522052026 | -56
10 | yellow | *ë/MID00/STRHello World/TIM1227270522052026 | -55
10 | yellow | *ë/MID00/STRHello World/TIM1227340522052026 | -55
10 | yellow | *ë/MID00/STRHello World/TIM1227480522052026 | -55
10 | yellow | *ë/MID00/STRHello World/TIM1227540522052026 | -54
15 | yellow | *ë/MID00/STRHello World/TIM1229080522052026 | -58
15 | yellow | *ë/MID00/STRHello World/TIM1229140522052026 | -58
15 | yellow | *ë/MID00/STRHello World/TIM1229210522052026 | -57
15 | yellow | *ë/MID00/STRHello World/TIM1229330522052026 | -58
15 | yellow | *ë/MID00/STRHello World/TIM1229400522052026 | -58
15 | yellow | *ë/MID00/STRHello World/TIM1229470522052026 | -58
15 | yellow | *ë/MID00/STRHello World/TIM1229540522052026 | -57
15 | yellow | *ë/MID00/STRHello World/TIM1230010522052026 | -58
15 | yellow | *ë/MID00/STRHello World/TIM1230070522052026 | -58
15 | yellow | *ë/MID00/STRHello World/TIM1230140522052026 | -59
15 | yellow | *ë/MID00/STRHello World/TIM1230210522052026 | -58
20 | yellow | *ë/MID00/STRHello World/TIM1231460522052026 | -60
20 | yellow | *ë/MID00/STRHello World/TIM1231530522052026 | -60
20 | yellow | *ë/MID00/STRHello World/TIM1232000522052026 | -60
20 | yellow | *ë/MID00/STRHello World/TIM1232070522052026 | -60
20 | yellow | *ë/MID00/STRHello World/TIM1232130522052026 | -60
20 | yellow | *ë/MID00/STRHello World/TIM1232200522052026 | -60
20 | yellow | *ë/MID00/STRHello World/TIM1232270522052026 | -60
20 | yellow | *ë/MID00/STRHello World/TIM1232340522052026 | -60
20 | yellow | *ë/MID00/STRHello World/TIM1232400522052026 | -61
20 | yellow | *ë/MID00/STRHello World/TIM1232470522052026 | -61
25 | yellow | *ë/MID00/STRHello World/TIM1233470522052026 | -64
25 | yellow | *ë/MID00/STRHello World/TIM1233540522052026 | -63
25 | yellow | *ë/MID00/STRHello World/TIM1234010522052026 | -62
25 | yellow | *ë/MID00/STRHello World/TIM1234070522052026 | -63
25 | yellow | *ë/MID00/STRHello World/TIM1234140522052026 | -64
25 | yellow | *ë/MID00/STRHello World/TIM1234220522052026 | -64
25 | yellow | *ë/MID00/STRHello World/TIM1234280522052026 | -64
25 | yellow | *ë/MID00/STRHello World/TIM1234350522052026 | -64
25 | yellow | *ë/MID00/STRHello World/TIM1234420522052026 | -62
25 | yellow | *ë/MID00/STRHello World/TIM1234490522052026 | -63
30 | yellow | *ë/MID00/STRHello World/TIM1235390522052026 | -67
30 | yellow | *ë/MID00/STRHello World/TIM1235460522052026 | -68
30 | yellow | *ë/MID00/STRHello World/TIM1235530522052026 | -67
30 | yellow | *ë/MID00/STRHello World/TIM1236000522052026 | -68
30 | yellow | *ë/MID00/STRHello World/TIM1236070522052026 | -68
30 | yellow | *ë/MID00/STRHello World/TIM1236140522052026 | -69
30 | yellow | *ë/MID00/STRHello World/TIM1236210522052026 | -72
30 | yellow | *ë/MID00/STRHello World/TIM1236280522052026 | -73
30 | yellow | *ë/MID00/STRHello World/TIM1236340522052026 | -73
30 | yellow | *ë/MID00/STRHello World/TIM1236410522052026 | -73
35 | yellow | *ë/MID00/STRHello World/TIM1237320522052026 | -74
35 | yellow | *ë/MID00/STRHello World/TIM1237390522052026 | -72
35 | yellow | *ë/MID00/STRHello World/TIM1237460522052026 | -74
35 | yellow | *ë/MID00/STRHello World/TIM1237520522052026 | -73
35 | yellow | *ë/MID00/STRHello World/TIM1237590522052026 | -72
35 | yellow | *ë/MID00/STRHello World/TIM1238060522052026 | -74
35 | yellow | *ë/MID00/STRHello World/TIM1238130522052026 | -73
35 | yellow | *ë/MID00/STRHello World/TIM1238200522052026 | -70
35 | yellow | *ë/MID00/STRHello World/TIM1238270522052026 | -74
35 | yellow | *ë/MID00/STRHello World/TIM1238350522052026 | -66
40 | yellow | *ë/MID00/STRHello World/TIM1239270522052026 | -74
40 | yellow | *ë/MID00/STRHello World/TIM1239340522052026 | -74
40 | yellow | *ë/MID00/STRHello World/TIM1239400522052026 | -72
40 | yellow | *ë/MID00/STRHello World/TIM1239470522052026 | -74
40 | yellow | *ë/MID00/STRHello World/TIM1239540522052026 | -72
40 | yellow | *ë/MID00/STRHello World/TIM1240010522052026 | -74
40 | yellow | *ë/MID00/STRHello World/TIM1240070522052026 | -73
40 | yellow | *ë/MID00/STRHello World/TIM1240140522052026 | -71
40 | yellow | *ë/MID00/STRHello World/TIM1240210522052026 | -70
40 | yellow | *ë/MID00/STRHello World/TIM1240270522052026 | -72
45 | yellow | *ë/MID00/STRHello World/TIM1312160522052026 | -74
45 | yellow | *ë/MID01/STRHello World/TIM1312190522052026 | -76
45 | yellow | *ë/MID02/STRHello World/TIM1312220522052026 | -74
45 | yellow | *ë/MID03/STRHello World/TIM1312250522052026 | -73
45 | yellow | *ë/MID04/STRHello World/TIM1312280522052026 | -74
45 | yellow | *ë/MID05/STRHello World/TIM1312310522052026 | -73
45 | yellow | *ë/MID06/STRHello World/TIM1312340522052026 | -74
45 | yellow | *ë/MID07/STRHello World/TIM1312380522052026 | -74
45 | yellow | *ë/MID08/STRHello World/TIM1312410522052026 | -75
45 | yellow | *ë/MID09/STRHello World/TIM1312440522052026 | -75
50 | yellow | *ë/MID00/STRHello World/TIM1313290522052026 | -74
50 | yellow | *ë/MID01/STRHello World/TIM1313330522052026 | -74
50 | yellow | *ë/MID02/STRHello World/TIM1313360522052026 | -74
50 | yellow | *ë/MID03/STRHello World/TIM1313390522052026 | -73
50 | yellow | *ë/MID04/STRHello World/TIM1313420522052026 | -74
50 | yellow | *ë/MID05/STRHello World/TIM1313450522052026 | -73
50 | yellow | *ë/MID06/STRHello World/TIM1313480522052026 | -73
50 | yellow | *ë/MID07/STRHello World/TIM1313510522052026 | -73
50 | yellow | *ë/MID08/STRHello World/TIM1313540522052026 | -73
50 | yellow | *ë/MID09/STRHello World/TIM1313570522052026 | -74
55 | yellow | *ë/MID00/STRHello World/TIM1314490522052026 | -74
55 | yellow | *ë/MID01/STRHello World/TIM1314520522052026 | -75
55 | yellow | *ë/MID02/STRHello World/TIM1314550522052026 | -75
55 | yellow | *ë/MID03/STRHello World/TIM1314590522052026 | -76
55 | yellow | *ë/MID04/STRHello World/TIM1315020522052026 | -76
55 | yellow | *ë/MID05/STRHello World/TIM1315050522052026 | -76
55 | yellow | *ë/MID06/STRHello World/TIM1315080522052026 | -76
55 | yellow | *ë/MID07/STRHello World/TIM1315110522052026 | -74
55 | yellow | *ë/MID08/STRHello World/TIM1315140522052026 | -76
55 | yellow | *ë/MID09/STRHello World/TIM1315170522052026 | -79
60 | yellow | *ë/MID00/STRHello World/TIM1316020522052026 | -81
60 | yellow | *ë/MID01/STRHello World/TIM1316050522052026 | -82
60 | yellow | *ë/MID02/STRHello World/TIM1316080522052026 | -80
60 | yellow | *ë/MID03/STRHello World/TIM1316110522052026 | -81
60 | yellow | *ë/MID04/STRHello World/TIM1316140522052026 | -83
60 | yellow | *ë/MID05/STRHello World/TIM1316170522052026 | -80
60 | yellow | *ë/MID06/STRHello World/TIM1316200522052026 | -80
60 | yellow | *ë/MID07/STRHello World/TIM1316230522052026 | -81
60 | yellow | *ë/MID08/STRHello World/TIM1316260522052026 | -80
60 | yellow | *ë/MID09/STRHello World/TIM1316300522052026 | -82
65 | yellow | *ë/MID00/STRHello World/TIM1317110522052026 | -79
65 | yellow | *ë/MID01/STRHello World/TIM1317140522052026 | -79
65 | yellow | *ë/MID02/STRHello World/TIM1317170522052026 | -79
65 | yellow | *ë/MID03/STRHello World/TIM1317200522052026 | -77
65 | yellow | *ë/MID04/STRHello World/TIM1317240522052026 | -80
65 | yellow | *ë/MID05/STRHello World/TIM1317270522052026 | -79
65 | yellow | *ë/MID06/STRHello World/TIM1317300522052026 | -79
65 | yellow | *ë/MID07/STRHello World/TIM1317330522052026 | -78
65 | yellow | *ë/MID08/STRHello World/TIM1317360522052026 | -79
65 | yellow | *ë/MID09/STRHello World/TIM1317390522052026 | -80
70 | yellow | *ë/MID00/STRHello World/TIM1318290522052026 | -74
70 | yellow | *ë/MID01/STRHello World/TIM1318320522052026 | -74
70 | yellow | *ë/MID02/STRHello World/TIM1318350522052026 | -74
70 | yellow | *ë/MID03/STRHello World/TIM1318380522052026 | -73
70 | yellow | *ë/MID04/STRHello World/TIM1318410522052026 | -73
70 | yellow | *ë/MID05/STRHello World/TIM1318440522052026 | -74
70 | yellow | *ë/MID06/STRHello World/TIM1318470522052026 | -74
70 | yellow | *ë/MID07/STRHello World/TIM1318500522052026 | -76
70 | yellow | *ë/MID08/STRHello World/TIM1318540522052026 | -74
70 | yellow | *ë/MID09/STRHello World/TIM1318570522052026 | -74
75 | yellow | *ë/MID00/STRHello World/TIM1334300522052026 | -84
75 | yellow | *ë/MID01/STRHello World/TIM1334330522052026 | -82
75 | yellow | *ë/MID02/STRHello World/TIM1334360522052026 | -80
75 | yellow | *ë/MID03/STRHello World/TIM1334400522052026 | -83
75 | yellow | *ë/MID04/STRHello World/TIM1334430522052026 | -80
75 | yellow | *ë/MID05/STRHello World/TIM1334460522052026 | -81
75 | yellow | *ë/MID06/STRHello World/TIM1334490522052026 | -81
75 | yellow | *ë/MID07/STRHello World/TIM1334520522052026 | -80
75 | yellow | *ë/MID08/STRHello World/TIM1334550522052026 | -80
75 | yellow | *ë/MID09/STRHello World/TIM1334580522052026 | -81
80 | yellow | *ë/MID00/STRHello World/TIM1335490522052026 | -89
80 | yellow | *ë/MID01/STRHello World/TIM1335520522052026 | -83
80 | yellow | *ë/MID02/STRHello World/TIM1335550522052026 | -86
80 | yellow | *ë/MID03/STRHello World/TIM1335580522052026 | -88
80 | yellow | *ë/MID04/STRHello World/TIM1336010522052026 | -86
85 | yellow | *ë/MID00/STRHello World/TIM1339050522052026 | -83
85 | yellow | *ë/MID01/STRHello World/TIM1339080522052026 | -85
85 | yellow | *ë/MID02/STRHello World/TIM1339110522052026 | -85
85 | yellow | *ë/MID03/STRHello World/TIM1339140522052026 | -84
85 | yellow | *ë/MID04/STRHello World/TIM1339180522052026 | -83
85 | yellow | *ë/MID05/STRHello World/TIM1339210522052026 | -87
85 | yellow | *ë/MID06/STRHello World/TIM1339240522052026 | -87
85 | yellow | *ë/MID07/STRHello World/TIM1339270522052026 | -88
85 | yellow | *ë/MID08/STRHello World/TIM1339300522052026 | -87
85 | yellow | *ë/MID09/STRHello World/TIM1339330522052026 | -89
90 | yellow | *ë/MID00/STRHello World/TIM1340400522052026 | -90
90 | yellow | *ë/MID01/STRHello World/TIM1340430522052026 | -84
90 | yellow | *ë/MID02/STRHello World/TIM1340470522052026 | -81
90 | yellow | *ë/MID03/STRHello World/TIM1340500522052026 | -83
90 | yellow | *ë/MID04/STRHello World/TIM1340530522052026 | -85
95 | yellow | *ë/MID00/STRHello World/TIM1342480522052026 | -79
95 | yellow | *ë/MID01/STRHello World/TIM1342510522052026 | -79
95 | yellow | *ë/MID02/STRHello World/TIM1342540522052026 | -79
95 | yellow | *ë/MID03/STRHello World/TIM1342570522052026 | -78
95 | yellow | *ë/MID04/STRHello World/TIM1343000522052026 | -78
95 | yellow | *ë/MID05/STRHello World/TIM1343040522052026 | -80
95 | yellow | *ë/MID06/STRHello World/TIM1343070522052026 | -79
95 | yellow | *ë/MID07/STRHello World/TIM1343100522052026 | -78
95 | yellow | *ë/MID08/STRHello World/TIM1343130522052026 | -78
95 | yellow | *ë/MID09/STRHello World/TIM1343160522052026 | -79
100 | yellow | *ë/MID00/STRHello World/TIM1343570522052026 | -75
100 | yellow | *ë/MID01/STRHello World/TIM1344010522052026 | -74
100 | yellow | *ë/MID02/STRHello World/TIM1344040522052026 | -75
100 | yellow | *ë/MID03/STRHello World/TIM1344070522052026 | -76
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

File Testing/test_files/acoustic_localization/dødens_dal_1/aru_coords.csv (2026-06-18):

 | x | y
mic1_cx63.418681_cy10.407074_synced.WAV | 0.0 | 0.0
mic2_cx63.418972_cy10.406313_synced.WAV | -38.74585528334137 | 31.471723878756166
mic3_cx63.419278_cy10.406895_synced.WAV | -10.395875738351606 | 66.31166220083833
mic4_cx63.418987_cy10.407657_synced.WAV | 28.302394953905605 | 34.72778086736798

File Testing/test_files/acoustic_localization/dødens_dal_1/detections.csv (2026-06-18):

file | start_time | end_time | Bank Swallow | Bohemian Waxwing | Coal Tit | Common Chaffinch | Common Gull | Common House-Martin | Common Redpoll | Common Scoter | Eurasian Blackbird | Eurasian Blackcap | Eurasian Blue Tit | Eurasian Coot | Eurasian Nuthatch | Eurasian Siskin | Eurasian Treecreeper | Eurasian Woodcock | European Greenfinch | European Pied Flycatcher | European Robin | Fieldfare | Great Spotted Woodpecker | Great Tit | Herring Gull | Little Ringed Plover | Mistle Thrush | Northern Lapwing | Ortolan Bunting | Pine Grosbeak | Redwing | Song Thrush | Tawny Owl | Tree Pipit | Wood Lark | Yellowhammer
mic1_cx63.418681_cy10.407074_synced.WAV | 0.0 | 3.0 | 0.0 | 0.0 | 0.0 | 0.0 | 0.0 | 0.0 | 0.0 | 0.0 | 0.0 | 0.0 | 0.0 | 0.0 | 0.0 | 0.0 | 0.0 | 0.0 | 0.0 | 0.0 | 0.0 | 0.0 | 0.0 | 0.0 | 0.0 | 0.0 | 0.0 | 0.0 | 0.0 | 0.0 | 0.0 | 0.0 | 0.0 | 0.0 | 0.0 | 0.0
mic1_cx63.418681_cy10.407074_synced.WAV | 3.0 | 6.0 | 0.0 | 0.0 | 0.0 | 0.0 | 0.0 | 0.0 | 0.0 | 0.0 | 0.0 | 0.0 | 0.0 | 0.0 | 0.0 | 0.0 | 0.0 | 0.0 | 0.0 | 0.0 | 0.0 | 0.0 | 0.0 | 0.0 | 0.0 | 0.0 | 0.0 | 0.0 | 0.0 | 0.0 | 0.0 | 0.0 | 0.0 | 0.0 | 0.0 | 0.0
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

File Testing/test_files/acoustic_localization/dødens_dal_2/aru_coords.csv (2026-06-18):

 | x | y
20260530_121816_MIC1_synced.WAV | 0.0 | 0.0
20260530_121929_MIC2_synced.WAV | -38.74585528334137 | 31.471723878756166
20260530_121853_MIC3_synced.WAV | -10.395875738351606 | 66.31166220083833
20260530_121810_MIC4_synced.WAV | 28.302394953905605 | 34.72778086736798

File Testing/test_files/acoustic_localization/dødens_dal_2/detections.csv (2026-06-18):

file | start_time | end_time | Bank Swallow | Brambling | Common Buzzard | Common Chaffinch | Common Goldeneye | Common Gull | Common House-Martin | Eurasian Blackbird | Eurasian Coot | Eurasian Jackdaw | Eurasian Magpie | European Greenfinch | European Robin | Fieldfare | Great Spotted Woodpecker | Hooded Crow | Northern Goshawk | Stock Dove | White Wagtail
20260530_121816_MIC1_synced.WAV | 0.0 | 3.0 | 0.0 | 0.0 | 0.0 | 0.0 | 0.0 | 0.0 | 0.0 | 0.0 | 0.0 | 0.0 | 0.0 | 0.0 | 0.0 | 0.0 | 0.0 | 0.0 | 0.0 | 0.0 | 0.0
20260530_121816_MIC1_synced.WAV | 3.0 | 6.0 | 0.0 | 0.0 | 0.0 | 0.0 | 0.0 | 0.0 | 0.0 | 0.0 | 0.0 | 0.0 | 0.0 | 0.0 | 0.0 | 0.0 | 0.0 | 0.0 | 0.0 | 0.0 | 0.0
20260530_121816_MIC1_synced.WAV | 6.0 | 9.0 | 0.0 | 0.0 | 0.0 | 0.0 | 0.0 | 0.0 | 0.0 | 0.0 | 0.0 | 0.0 | 0.0 | 0.0 | 0.0 | 0.0 | 0.0 | 0.0 | 0.0 | 0.0 | 0.0
20260530_121816_MIC1_synced.WAV | 9.0 | 12.0 | 0.0 | 0.0 | 0.0 | 0.0 | 0.0 | 0.0 | 0.0 | 0.0 | 0.0 | 0.0 | 0.0 | 0.0 | 0.0 | 0.0 | 0.0 | 0.0 | 0.0 | 0.0 | 0.0
20260530_121816_MIC1_synced.WAV | 12.0 | 15.0 | 0.0 | 0.0 | 0.0 | 0.0 | 0.0 | 0.0 | 0.0 | 0.0 | 0.0 | 0.0 | 0.0 | 0.0 | 0.0 | 0.0 | 0.0 | 0.0 | 0.0 | 0.0 | 0.0
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

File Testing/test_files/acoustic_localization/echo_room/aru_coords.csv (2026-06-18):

 | x | y
mic1_x0_y0_synced.WAV | 0.0 | 0.0
mic2_x0_y-3.35_synced.WAV | 0.0 | -3.35
mic3_x-3.65_y-3.31_synced.WAV | -3.65 | -3.31
mic4_x-3.62_y0_synced.WAV | -3.62 | 0.0

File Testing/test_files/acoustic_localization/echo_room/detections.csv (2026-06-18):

file | start_time | end_time | Common Grasshopper-Warbler | Lesser Spotted Woodpecker
mic1_x0_y0_synced.WAV | 0.0 | 3.0 | 0.0 | 0.0
mic1_x0_y0_synced.WAV | 3.0 | 6.0 | 0.0 | 0.0
mic1_x0_y0_synced.WAV | 6.0 | 9.0 | 0.0 | 0.0
mic1_x0_y0_synced.WAV | 9.0 | 12.0 | 0.0 | 0.0
mic1_x0_y0_synced.WAV | 12.0 | 15.0 | 0.0 | 0.0
mic1_x0_y0_synced.WAV | 15.0 | 18.0 | 0.0 | 0.0
mic1_x0_y0_synced.WAV | 18.0 | 21.0 | 0.0 | 0.0
mic1_x0_y0_synced.WAV | 21.0 | 24.0 | 0.0 | 0.0
mic1_x0_y0_synced.WAV | 24.0 | 27.0 | 0.0 | 0.0
mic1_x0_y0_synced.WAV | 27.0 | 30.0 | 0.0 | 0.0
mic1_x0_y0_synced.WAV | 30.0 | 33.0 | 0.0 | 0.0
mic1_x0_y0_synced.WAV | 33.0 | 36.0 | 0.0 | 0.0
mic1_x0_y0_synced.WAV | 36.0 | 39.0 | 0.0 | 0.0
mic1_x0_y0_synced.WAV | 39.0 | 42.0 | 0.0 | 0.0
mic1_x0_y0_synced.WAV | 42.0 | 45.0 | 0.0 | 0.0
mic1_x0_y0_synced.WAV | 45.0 | 48.0 | 0.0 | 0.0
mic1_x0_y0_synced.WAV | 48.0 | 51.0 | 0.0 | 0.0
mic1_x0_y0_synced.WAV | 51.0 | 54.0 | 0.0 | 0.0
mic1_x0_y0_synced.WAV | 54.0 | 57.0 | 0.0 | 0.0
mic1_x0_y0_synced.WAV | 57.0 | 60.0 | 0.0 | 0.0
mic1_x0_y0_synced.WAV | 60.0 | 63.0 | 0.0 | 0.0
mic1_x0_y0_synced.WAV | 63.0 | 66.0 | 0.0 | 0.0
mic1_x0_y0_synced.WAV | 66.0 | 69.0 | 0.0 | 0.0
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

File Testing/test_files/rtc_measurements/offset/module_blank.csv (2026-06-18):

real_datetime | module_datetime
2026-05-20 11:22:02 | 2026-05-20 09:22:01
2026-05-20 11:22:44 | 2026-05-20 09:22:43
2026-05-20 11:23:11 | 2026-05-20 09:23:10
2026-05-20 11:23:39 | 2026-05-20 09:23:38
2026-05-20 11:24:12 | 2026-05-20 09:24:11
2026-05-20 11:24:40 | 2026-05-20 09:24:40
2026-05-20 11:25:10 | 2026-05-20 09:25:09
2026-05-20 11:25:37 | 2026-05-20 09:25:37
2026-05-20 11:26:04 | 2026-05-20 09:26:04
2026-05-20 11:26:34 | 2026-05-20 09:26:33

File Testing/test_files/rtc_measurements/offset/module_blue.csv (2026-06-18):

real_datetime | module_datetime
2026-05-20 10:41:00 | 2026-05-20 08:40:59
2026-05-20 10:41:35 | 2026-05-20 08:41:35
2026-05-20 10:42:45 | 2026-05-20 08:42:44
2026-05-20 10:44:25 | 2026-05-20 08:44:25
2026-05-20 10:45:33 | 2026-05-20 08:45:32
2026-05-20 10:46:57 | 2026-05-20 08:46:57
2026-05-20 10:47:46 | 2026-05-20 08:47:46
2026-05-20 10:48:56 | 2026-05-20 08:48:55
2026-05-20 10:49:32 | 2026-05-20 08:49:31
2026-05-20 11:09:59 | 2026-05-20 09:09:59

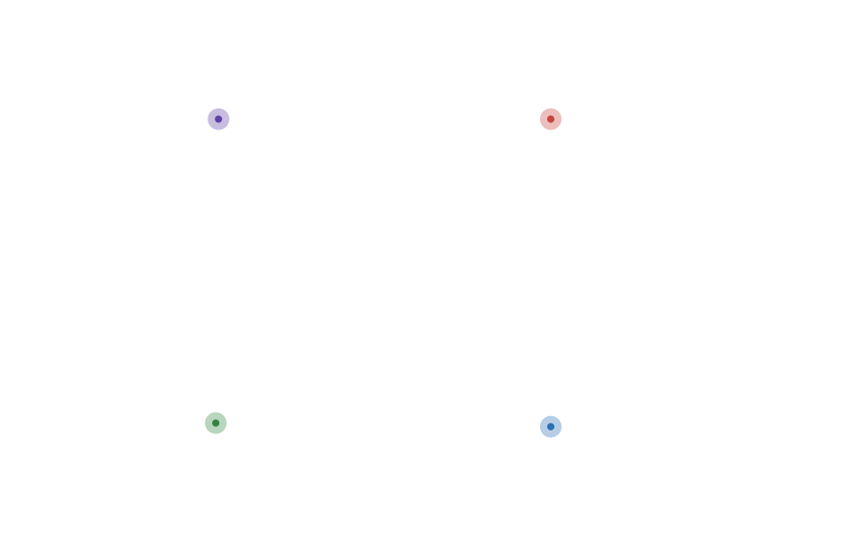
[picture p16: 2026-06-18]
Testing/test_files/acoustic_localization/echo_room/SATELLITE_IMAGE.png

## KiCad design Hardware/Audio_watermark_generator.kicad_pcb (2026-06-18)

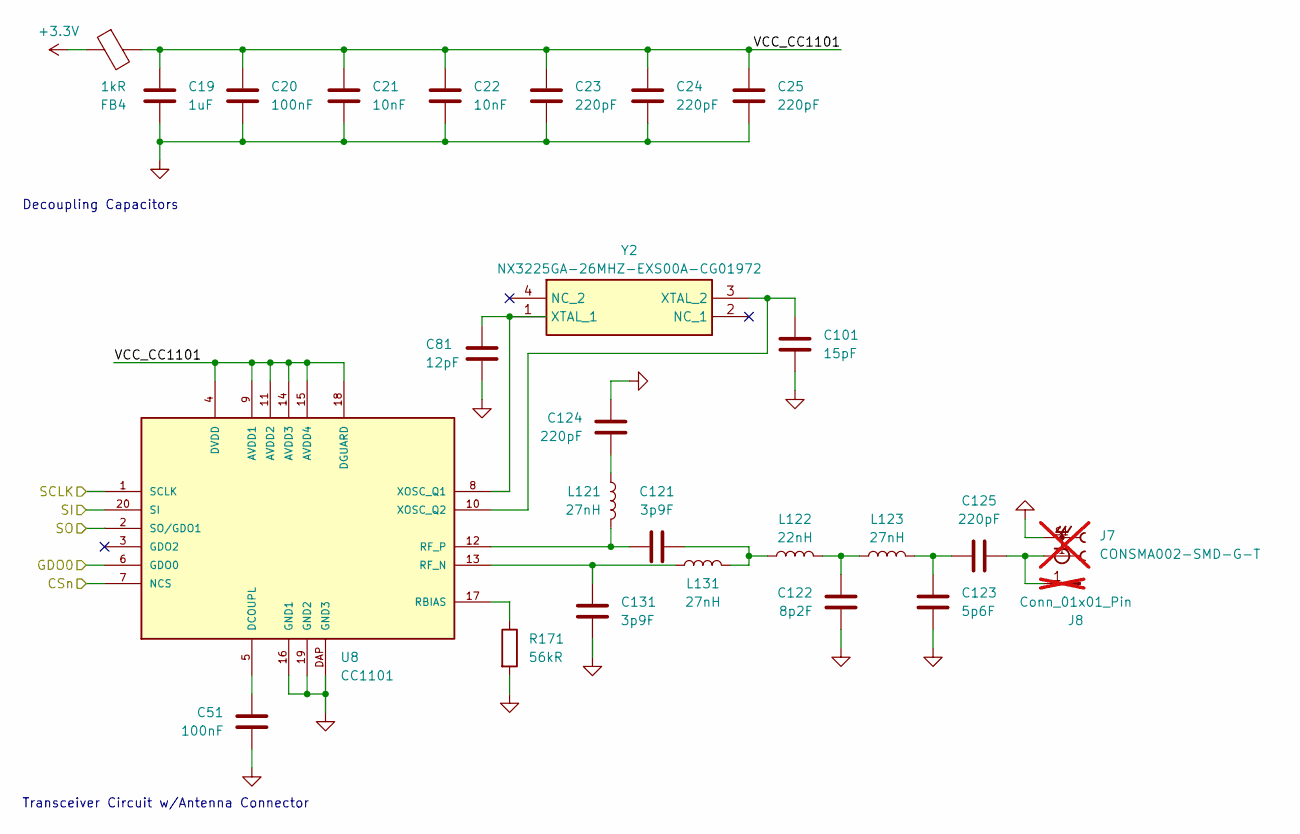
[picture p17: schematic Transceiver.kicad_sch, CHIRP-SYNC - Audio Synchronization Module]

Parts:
C19: 1uF; C_0805_2012Metric; LCSC Part # C77079
C20, C51: 100nF; C_0402_1005Metric; LCSC Part # C1525
C21, C22: 10nF; C_0402_1005Metric; LCSC Part # C15195
C23, C24, C25, C124, C125: 220pF; C_0402_1005Metric; LCSC Part # C71693
C81: 12pF; C_0402_1005Metric; LCSC Part # C1547
C101: 15pF; C_0402_1005Metric; LCSC Part # C1548
C121, C131: 3p9F; C_0402_1005Metric; LCSC Part # C85940
C122: 8p2F; C_0402_1005Metric; LCSC Part # C76984
C123: 5p6F; C_0402_1005Metric; LCSC Part # C85941
FB4: 1kR; L_0402_1005Metric; LCSC Part # C76889
J7: CONSMA002-SMD-G-T; LINX_CONSMA002-SMD-G-T; LCSC Part # C6886897; not fitted
J8: Conn_01x01_Pin; TestPoint_Pad_2.0x2.0mm; not fitted
L121, L123, L131: 27nH; L_0402_1005Metric; LCSC Part # C12669
L122: 22nH; L_0402_1005Metric; LCSC Part # C12670
R171: 56kR; R_0402_1005Metric; LCSC Part # C71703
U8: CC1101; LCSC Part # C29953
Y2: NX3225GA-26MHZ-EXS00A-CG01972; Crystal_SMD_3225-4Pin_3.2x2.5mm; Manufacturer_Part_Number NX3225GA-26MHZ-EXS00A-CG01972; LCSC Part # C485372

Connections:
+3.3V: FB4.1; also elsewhere on the board
/STM32/SPI_CSN: U8.7 (NCS); also elsewhere on the board
/STM32/SPI_GOD0: U8.6 (GDO0); also elsewhere on the board
/STM32/SPI_MISO: U8.20 (SI); also elsewhere on the board
/STM32/SPI_MOSI: U8.2 (SO/GDO1); also elsewhere on the board
/STM32/SPI_SCK: U8.1 (SCLK); also elsewhere on the board
/Transceiver/VCC_CC1101: C19.2, C20.2, C21.2, C22.2, C23.2, C24.2, C25.2, FB4.2, U8.4 (DVDD), U8.9 (AVDD1), U8.11 (AVDD2), U8.14 (AVDD3), U8.15 (AVDD4), U8.18 (DGUARD)
GND: C19.1, C20.1, C21.1, C22.1, C23.1, C24.1, C25.1, C51.2, C81.1, C101.2, C122.2, C123.2, C124.1, C131.1, J7.S1, J7.S2, R171.2, U8.16 (GND1), U8.19 (GND2), U8.DAP (GND3); also elsewhere on the board
unnamed: C121.2, L122.1, L131.1
unnamed: C122.1, L122.2, L123.1
unnamed: C123.1, C125.1, L123.2
unnamed: C124.2, L121.2
unnamed: C125.2, J7.1, J8.1
unnamed: C51.1, U8.5 (DCOUPL)
unnamed: R171.1, U8.17 (RBIAS)
unnamed: C131.2, L131.2, U8.13 (RF_N)
unnamed: C121.1, L121.1, U8.12 (RF_P)
unnamed: C81.2, U8.8 (XOSC_Q1), Y2.1 (XTAL_1)
unnamed: C101.1, U8.10 (XOSC_Q2), Y2.3 (XTAL_2)

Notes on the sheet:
Decoupling Capacitors
Transceiver Circuit w/Antenna Connector

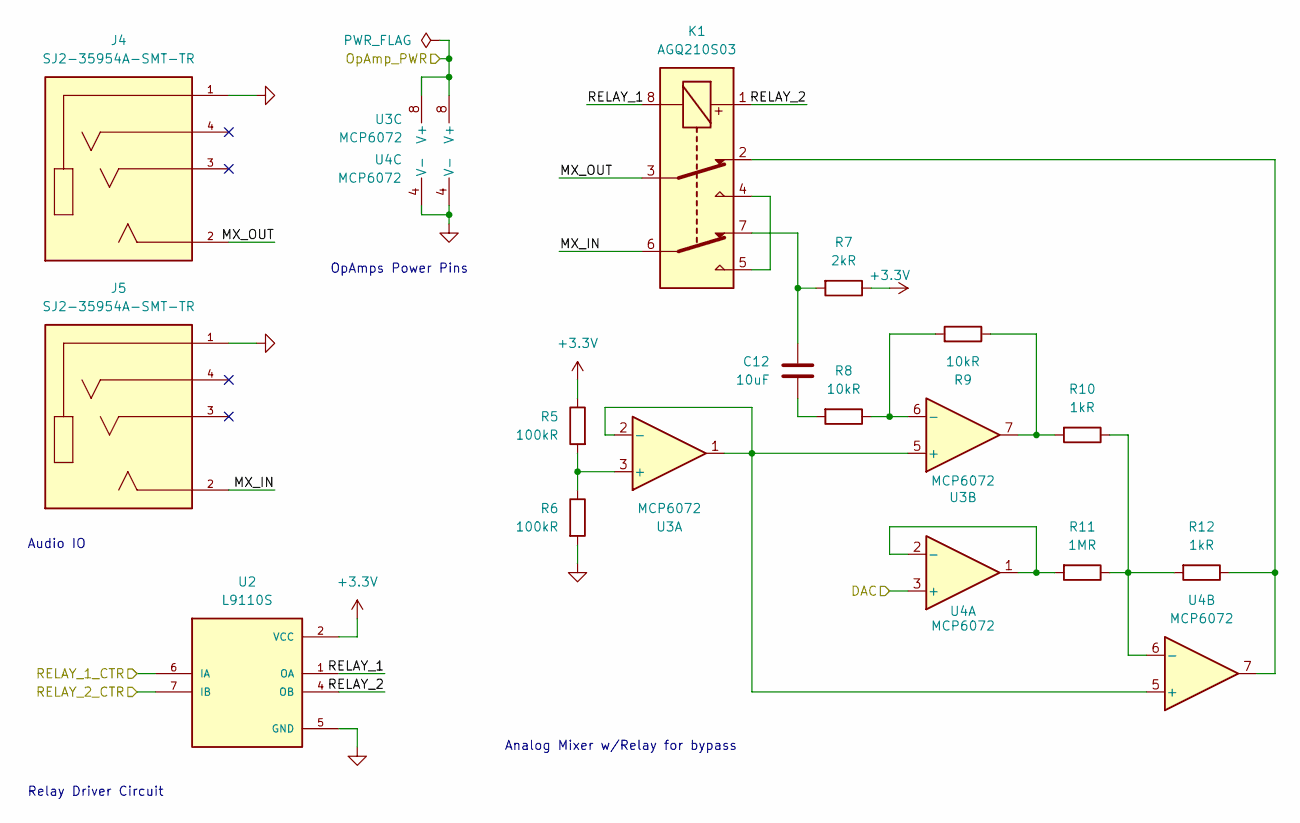
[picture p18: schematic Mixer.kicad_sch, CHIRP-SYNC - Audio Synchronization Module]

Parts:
C12: 10uF; C_0805_2012Metric; LCSC Part # C440198
J4, J5: SJ2-35954A-SMT-TR; CUI_SJ2-35954A-SMT-TR; PARTREV 1.04; LCSC Part # C4992345
K1: AGQ210S03; LCSC Part # C5582831
R5, R6: 100kR; R_0805_2012Metric; LCSC Part # C25611
R7: 2kR; R_0805_2012Metric; LCSC Part # C17604
R8, R9: 10kR; R_0805_2012Metric; LCSC Part # C17414
R10, R12: 1kR; R_0805_2012Metric; LCSC Part # C17513
R11: 1MR; R_0805_2012Metric; LCSC Part # C17514
U2: L9110S; SOIC127P599X172-8N; PARTREV NA; LCSC Part # C725793
U3, U4: MCP6072; SOIC127P599X175-8N; LCSC Part # C122875

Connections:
+3.3V: R5.1, R7.1, U2.2 (VCC), U2.3 (VCC); also elsewhere on the board
/Mixer/DAC: U4.3 (+); also elsewhere on the board
/Mixer/MX_IN: J5.2, K1.6
/Mixer/MX_OUT: J4.2, K1.3
/Mixer/OpAmp_PWR: U3.8 (V+), U4.8 (V+); also elsewhere on the board
/Mixer/RELAY_1: K1.8, U2.1 (OA)
/Mixer/RELAY_1_CTR: U2.6 (IA); also elsewhere on the board
/Mixer/RELAY_2: K1.1, U2.4 (OB)
/Mixer/RELAY_2_CTR: U2.7 (IB); also elsewhere on the board
GND: J4.1, J5.1, R6.2, U2.5 (GND), U2.8 (GND), U3.4 (V-), U4.4 (V-); also elsewhere on the board
unnamed: C12.1, K1.7, R7.2
unnamed: C12.2, R8.2
unnamed: K1.2, R12.1, U4.7
unnamed: K1.4, K1.5
unnamed: R9.1, R10.2, U3.7
unnamed: R5.2, R6.1, U3.3 (+)
unnamed: U3.1, U3.2 (-), U3.5 (+), U4.5 (+)
unnamed: R8.1, R9.2, U3.6 (-)
unnamed: R11.2, U4.1, U4.2 (-)
unnamed: R10.1, R11.1, R12.2, U4.6 (-)

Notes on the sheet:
OpAmps Power Pins
Audio IO
Analog Mixer w/Relay for bypass
Relay Driver Circuit

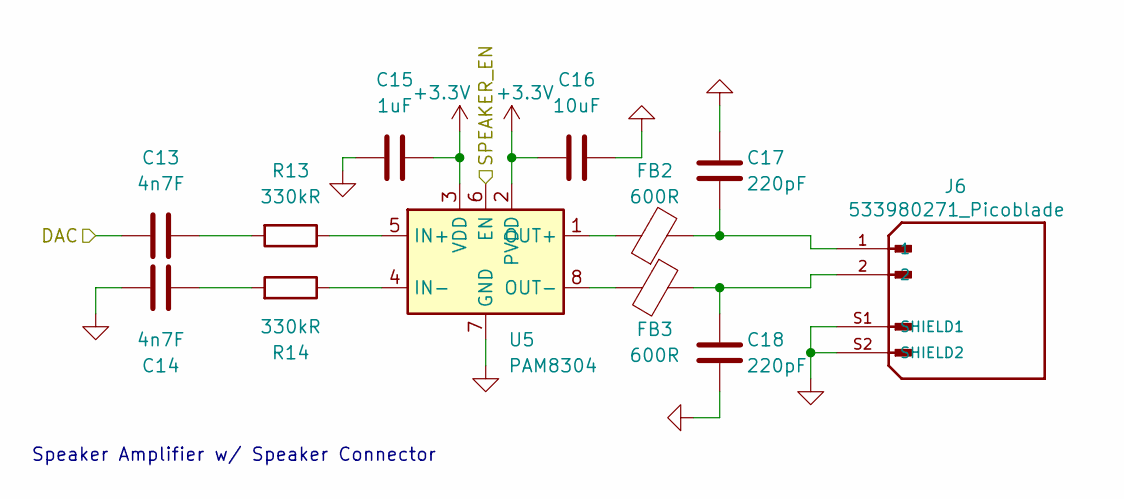
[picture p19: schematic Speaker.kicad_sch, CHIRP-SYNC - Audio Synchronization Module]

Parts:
C13, C14: 4n7F; C_0603_1608Metric; LCSC Part # C53987
C15: 1uF; C_0603_1608Metric; LCSC Part # C15849
C16: 10uF; C_0805_2012Metric; LCSC Part # C440198
C17, C18: 220pF; C_0402_1005Metric; LCSC Part # C71693
FB2, FB3: 600R; L_0603_1608Metric; LCSC Part # C1002
J6: 533980271_Picoblade; MOLEX_533980271_Picoblade; PARTREV A; LCSC Part # C122410
R13, R14: 330kR; R_0805_2012Metric; LCSC Part # C17629
U5: PAM8304; PAM8304ASR; LCSC Part # C581342

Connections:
+3.3V: C15.2, C16.1, U5.2 (PVDD), U5.3 (VDD); also elsewhere on the board
/Mixer/DAC: C13.1; also elsewhere on the board
/STM32/SPEAKER_EN: U5.6 (EN); also elsewhere on the board
GND: C14.1, C15.1, C16.2, C17.1, C18.2, J6.S1 (SHIELD1), J6.S2 (SHIELD2), U5.7 (GND); also elsewhere on the board
unnamed: C13.2, R13.2
unnamed: C14.2, R14.2
unnamed: C17.2, FB2.2, J6.1
unnamed: C18.1, FB3.1, J6.2
unnamed: R13.1, U5.5 (IN+)
unnamed: R14.1, U5.4 (IN-)
unnamed: FB2.1, U5.1 (OUT+)
unnamed: FB3.2, U5.8 (OUT-)

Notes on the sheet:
Speaker Amplifier w/ Speaker Connector

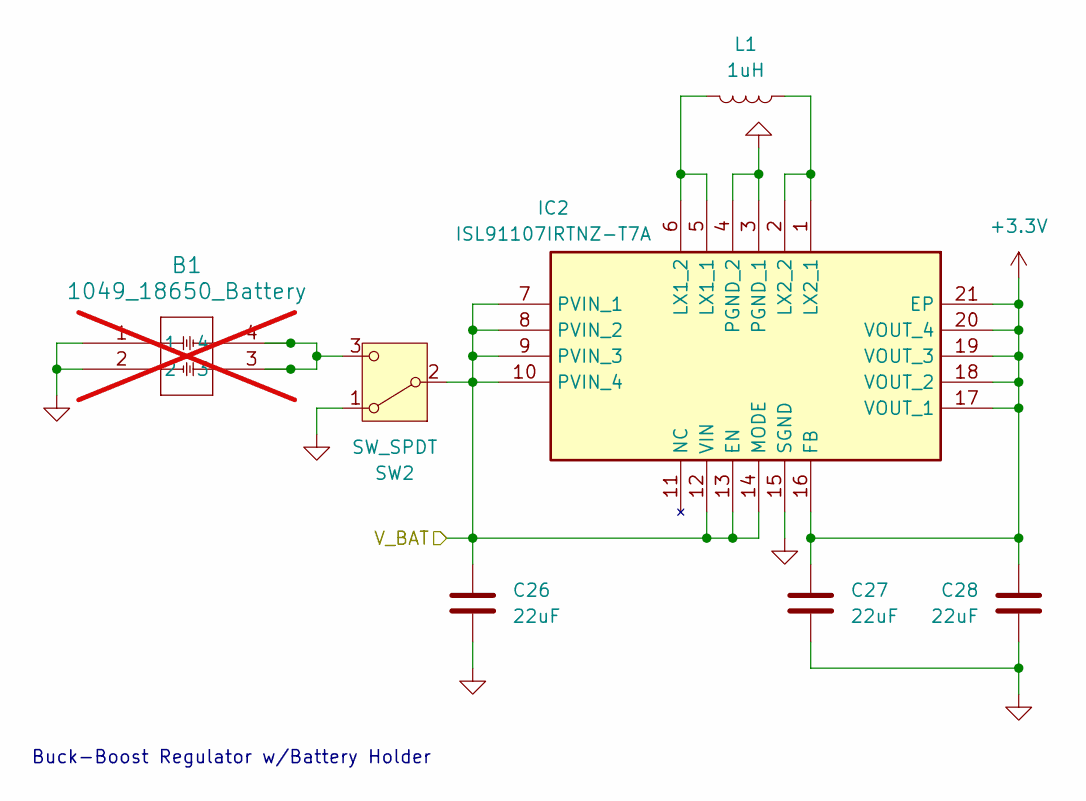
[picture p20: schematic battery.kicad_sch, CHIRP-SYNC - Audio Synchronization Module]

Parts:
B1: 1049_18650_Battery; 1049_KEY_1; not fitted
C26, C27, C28: 22uF; C_0603_1608Metric; LCSC Part # C84419
IC2: ISL91107IRTNZ-T7A; QFN50P300X400X80-21N; Manufacturer_Part_Number ISL91107IRTNZ-T7A; Mouser Part Number 968-ISL91107IRTNZT7A
L1: 1uH; L_1008_2520Metric; LCSC Part # C470857
SW2: SW_SPDT; SW_SPDT_PCM12; LCSC Part # C221841

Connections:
+3.3V: C27.1, C28.2, IC2.16 (FB), IC2.17 (VOUT_1), IC2.18 (VOUT_2), IC2.19 (VOUT_3), IC2.20 (VOUT_4), IC2.21 (EP); also elsewhere on the board
/Battery/V_BAT: C26.1, IC2.7 (PVIN_1), IC2.8 (PVIN_2), IC2.9 (PVIN_3), IC2.10 (PVIN_4), IC2.12 (VIN), IC2.13 (EN), IC2.14 (MODE), SW2.2 (B); also elsewhere on the board
GND: B1.1, B1.2, C26.2, C27.2, C28.1, IC2.3 (PGND_1), IC2.4 (PGND_2), IC2.15 (SGND), SW2.1 (A); also elsewhere on the board
unnamed: IC2.5 (LX1_1), IC2.6 (LX1_2), L1.2
unnamed: IC2.1 (LX2_1), IC2.2 (LX2_2), L1.1
unnamed: B1.3, B1.4, SW2.3 (C)

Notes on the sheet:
Buck-Boost Regulator w/Battery Holder

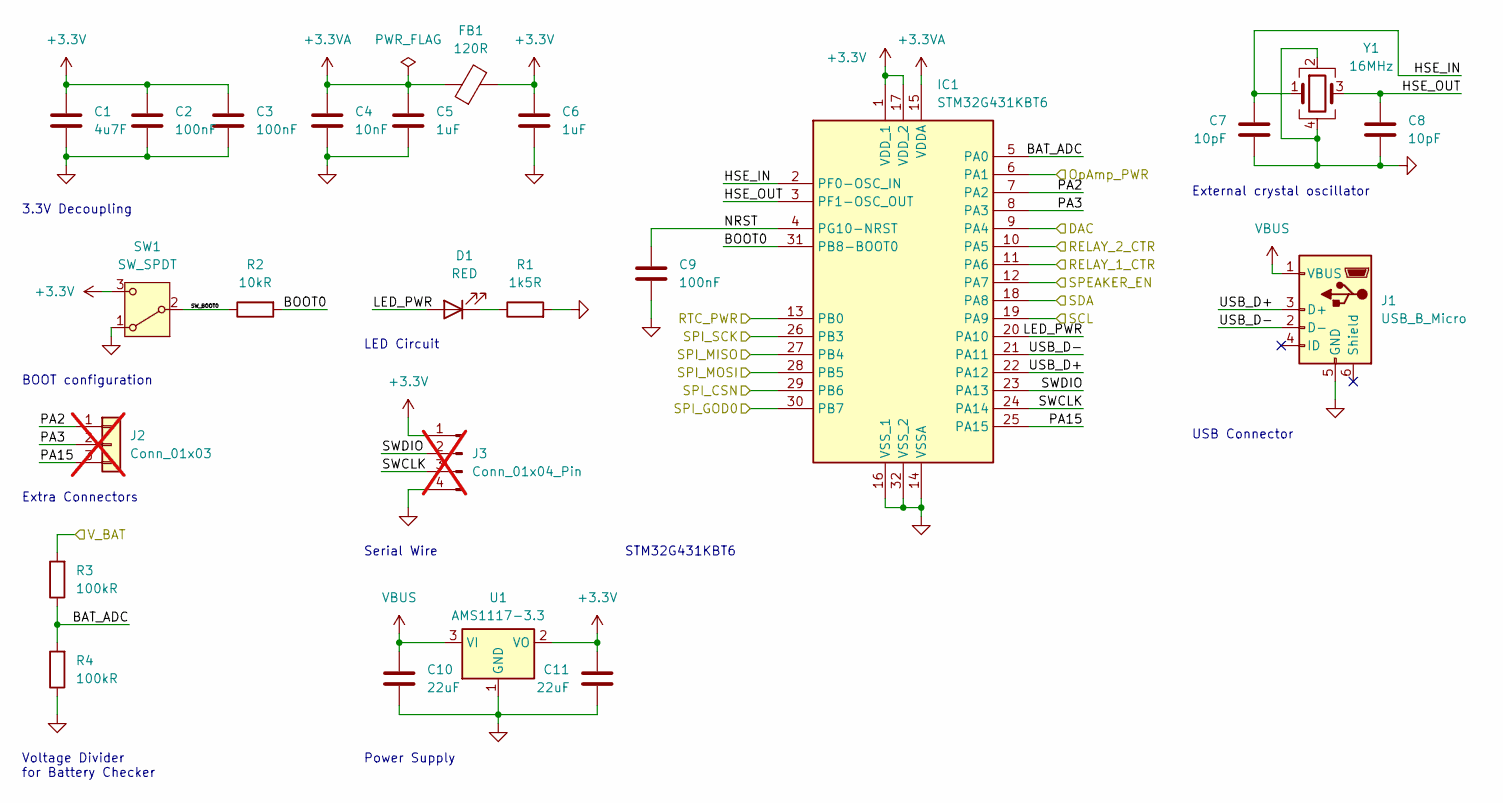
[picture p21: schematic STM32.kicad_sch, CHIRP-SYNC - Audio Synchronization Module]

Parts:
C1: 4u7F; C_0603_1608Metric; LCSC Part # C19666
C2, C3, C9: 100nF; C_0402_1005Metric; LCSC Part # C1525
C4: 10nF; C_0402_1005Metric; LCSC Part # C15195
C5, C6: 1uF; C_0603_1608Metric; LCSC Part # C15849
C7, C8: 10pF; C_0402_1005Metric; LCSC Part # C32949
C10, C11: 22uF; C_0805_2012Metric; LCSC Part # C45783
D1: RED; LED_0603_1608Metric; LCSC Part # C2286
FB1: 120R; L_0603_1608Metric; LCSC Part # C14709
IC1: STM32G431KBT6; Manufacturer_Part_Number STM32G431KBT6; Mouser Part Number 511-STM32G431KBT6
J1: USB_B_Micro; USB_Micro-B_Wuerth_629105150521; LCSC Part # C2894326
J2: Conn_01x03; PinHeader_1x03_P2.54mm_Vertical_SMD_Pin1Right; not fitted
J3: Conn_01x04_Pin; PinHeader_1x04_P2.54mm_Vertical; not fitted
R1: 1k5R; R_0402_1005Metric; LCSC Part # C25867
R2: 10kR; R_0402_1005Metric; LCSC Part # C25744
R3, R4: 100kR; R_0805_2012Metric; LCSC Part # C25611
SW1: SW_SPDT; SW_SPDT_PCM12; LCSC Part # C221841
U1: AMS1117-3.3; SOT-223-3_TabPin2; LCSC Part # C6186
Y1: 16MHz; Crystal_SMD_3225-4Pin_3.2x2.5mm; LCSC Part # C112972

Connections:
+3.3V: C1.1, C2.1, C3.1, C6.1, C11.1, FB1.2, IC1.1 (VDD_1), IC1.17 (VDD_2), J3.1, SW1.3 (C), U1.2 (VO); also elsewhere on the board
+3.3VA: C4.1, C5.1, FB1.1, IC1.15 (VDDA)
/Battery/V_BAT: R3.2; also elsewhere on the board
/Mixer/DAC: IC1.9 (PA4); also elsewhere on the board
/Mixer/OpAmp_PWR: IC1.6 (PA1); also elsewhere on the board
/Mixer/RELAY_1_CTR: IC1.11 (PA6); also elsewhere on the board
/Mixer/RELAY_2_CTR: IC1.10 (PA5); also elsewhere on the board
/RTC/RTC_PWR: IC1.13 (PB0); also elsewhere on the board
/RTC/SCL: IC1.19 (PA9); also elsewhere on the board
/RTC/SDA: IC1.18 (PA8); also elsewhere on the board
/STM32/BAT_ADC: IC1.5 (PA0), R3.1, R4.2
/STM32/BOOT0: IC1.31 (PB8-BOOT0), R2.2
/STM32/HSE_IN: C7.2, IC1.2 (PF0-OSC_IN), Y1.1
/STM32/HSE_OUT: C8.1, IC1.3 (PF1-OSC_OUT), Y1.3
/STM32/LED_PWR: D1.2 (A), IC1.20 (PA10)
/STM32/NRST: C9.1, IC1.4 (PG10-NRST)
/STM32/PA2: IC1.7 (PA2), J2.1
/STM32/PA3: IC1.8 (PA3), J2.2
/STM32/PA15: IC1.25 (PA15), J2.3
/STM32/SPEAKER_EN: IC1.12 (PA7); also elsewhere on the board
/STM32/SPI_CSN: IC1.29 (PB6); also elsewhere on the board
/STM32/SPI_GOD0: IC1.30 (PB7); also elsewhere on the board
/STM32/SPI_MISO: IC1.27 (PB4); also elsewhere on the board
/STM32/SPI_MOSI: IC1.28 (PB5); also elsewhere on the board
/STM32/SPI_SCK: IC1.26 (PB3); also elsewhere on the board
/STM32/SWCLK: IC1.24 (PA14), J3.3
/STM32/SWDIO: IC1.23 (PA13), J3.2
/STM32/SW_BOOT0: R2.1, SW1.2 (B)
/STM32/USB_D+: IC1.22 (PA12), J1.3 (D+)
/STM32/USB_D-: IC1.21 (PA11), J1.2 (D-)
GND: C1.2, C2.2, C3.2, C4.2, C5.2, C6.2, C7.1, C8.2, C9.2, C10.2, C11.2, IC1.14 (VSSA), IC1.16 (VSS_1), IC1.32 (VSS_2), J1.5 (GND), J3.4, R1.2, R4.1, SW1.1 (A), U1.1 (GND), Y1.2, Y1.4; also elsewhere on the board
unnamed: D1.1 (K), R1.1
VBUS: C10.1, J1.1 (VBUS), U1.3 (VI)

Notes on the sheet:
Power Supply
STM32G431KBT6
USB Connector
LED Circuit
BOOT configuration
Voltage Divider for Battery Checker
External crystal oscillator
Extra Connectors
Serial Wire
3.3V Decoupling

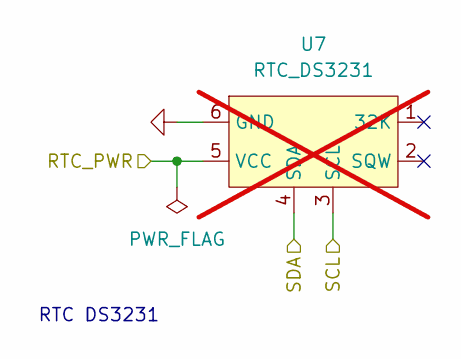
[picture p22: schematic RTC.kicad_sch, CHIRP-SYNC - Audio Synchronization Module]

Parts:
U7: RTC_DS3231; PinHeader_1x06_P2.54mm_DS3231; not fitted

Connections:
/RTC/RTC_PWR: U7.5 (VCC); also elsewhere on the board
/RTC/SCL: U7.3 (SCL); also elsewhere on the board
/RTC/SDA: U7.4 (SDA); also elsewhere on the board
GND: U7.6 (GND); also elsewhere on the board

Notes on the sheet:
RTC DS3231

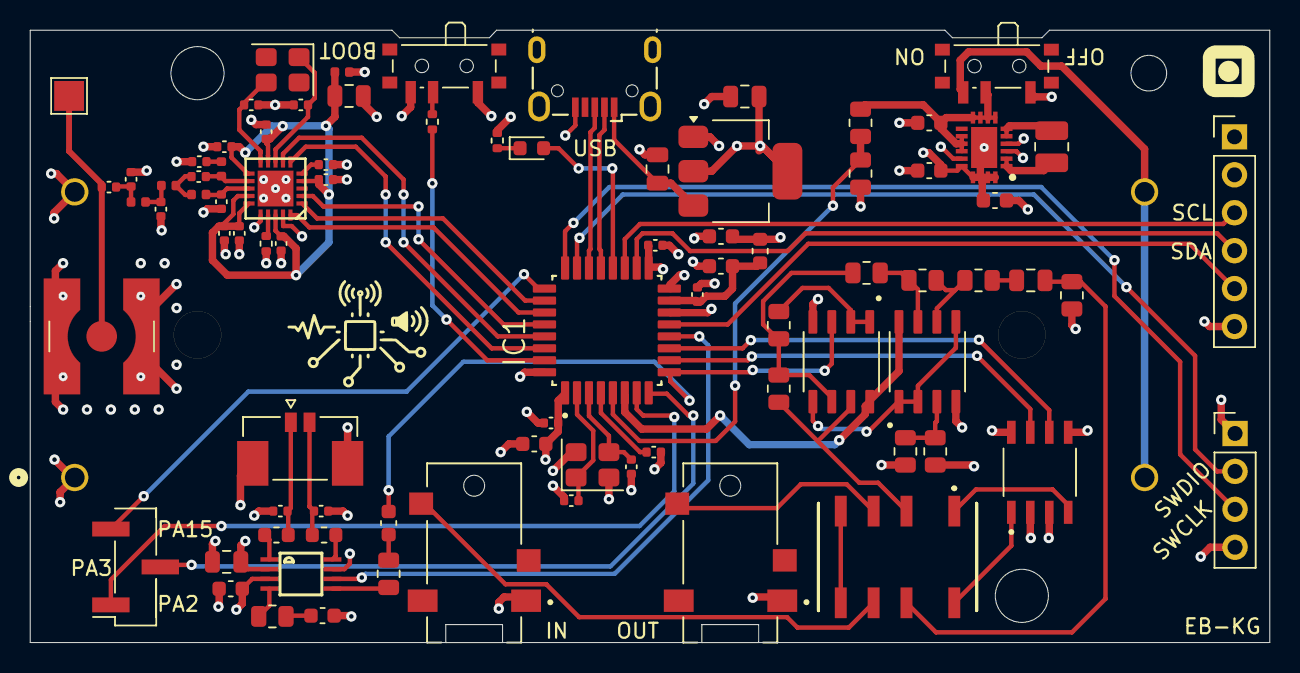
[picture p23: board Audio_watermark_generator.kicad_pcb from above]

Board: 4 copper layers, 83.0 x 41.0 mm, 85 parts (1 on the bottom side), 70 nets.

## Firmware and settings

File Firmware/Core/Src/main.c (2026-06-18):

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
/* Includes ------------------------------------------------------------------*/
#include "main.h"
#include "speaker.h"
#include "usb_device.h"

/* USER CODE BEGIN Includes */

#include "battery.h"
#include "cc1101.h"
#include "cc1101_config.h"
#include "ds3231.h"
#include "error_codes.h"
#include "flash_flag.h"
#include "frequency_config.h"
#include "led_feedback.h"
#include "log.h"
#include "opamps.h"
#include "radio.h"
#include "reed_solomon.h"
#include "relay.h"
#include "speaker.h"
#include "user_config.h"
#include "wakeup.h"

#include <cmsis_gcc.h>
#include <math.h>
#include <stdbool.h>
#include <stddef.h>
#include <stdint.h>
#include <stdio.h>
#include <stdlib.h>
#include <stm32g431xx.h>
#include <stm32g4xx.h>
#include <stm32g4xx_hal.h>
#include <stm32g4xx_hal_dac.h>
#include <stm32g4xx_hal_def.h>
#include <stm32g4xx_hal_gpio.h>
#include <string.h>
#include <sys/_intsup.h>
#include <sys/types.h>
#include <unistd.h>
#include <usbd_cdc_if.h>

/* USER CODE END Includes */

/* USER CODE BEGIN PD */

#define pi 3.14159265358979323846f

#define LEN_IF(cond, lit) ((cond) ? (sizeof(lit) - 1u) : 0u)

#define MAX_NUM_CHARS                                                          \
  (LEN_IF(INCLUDE_USER_STRING, "/STR" USER_STRING) +                           \
   LEN_IF(INCLUDE_DEVICE_ID, "/DID0000") +                                     \
   LEN_IF(INCLUDE_LOCATION, "/LOC00.0000,00.0000") +                           \
   LEN_IF(INCLUDE_TEMPERATURE, "/TMP000") +                                    \
   LEN_IF(INCLUDE_TIME, "/TIM00000000000000") + 4u)

#define MAX_PAYLOAD_BYTES (MAX_NUM_CHARS + RS_ERROR_CORRECTION_SYMBOLS)
#define BITSTREAM_LENGTH (1u + (MAX_PAYLOAD_BYTES * 8u) + 8u)

#define BIT_POLARITY 0

#define DS3231_ADDR (0x68 << 1) // 7-bit addr shifted for HAL
#define T4B_I2C_ADDR_7BIT 0x20
#define T4B_I2C_ADDR_HAL (T4B_I2C_ADDR_7BIT << 1) // 0x40 for HAL

#define DIV_FLOOR(n, d) ((uint32_t)((n) / (d)))
#define DIV_ROUND(n, d) ((uint32_t)(((n) + ((d) / 2u)) / (d)))

#define OUTPUT_SEGMENT 500
#define BUFFER_SIZE (OUTPUT_SEGMENT * 5)

#define SYNC_DELAY_MS 350

/* USER CODE END PD */

ADC_HandleTypeDef hadc1;

DAC_HandleTypeDef hdac1;
DMA_HandleTypeDef hdma_dac1_ch1;

I2C_HandleTypeDef hi2c2;

RTC_HandleTypeDef hrtc;

TIM_HandleTypeDef htim2;
TIM_HandleTypeDef htim6;

UART_HandleTypeDef huart2;

/* USER CODE BEGIN PV */

char input_string[MAX_NUM_CHARS] = {0};

uint8_t bitstream[BITSTREAM_LENGTH] = {0};

volatile uint8_t active_done = 0;

rtc_time_t now = {.seconds = 0,
                  .minutes = 0,
                  .hours = 0,
                  .day = 4,
                  .date = 1,
                  .month = 1,
                  .year = 1970};

int8_t temp_int = 99;

static uint32_t sine_val_low[LUT_LOW_SAMPLES];
static uint32_t sine_val_high[LUT_HIGH_SAMPLES];
static uint32_t dc_mid[LUT_LOW_SAMPLES];

uint32_t fs = 0;
float total_time = 0.0;

typedef struct {
  size_t bit_index;
  size_t current_period;
  size_t current_index;
} FillResult;

__ALIGN_BEGIN uint32_t output_buffer[BUFFER_SIZE] __ALIGN_END;

volatile bool tx_active = true;
volatile size_t current_bitstream_index = 0;
volatile size_t current_sine_period = 0;
volatile size_t current_sine_index = 0;
FillResult result;

uint8_t transmission[256] = {0};
int dBm_value = 0;

freq_pair_t freq_pair = {0};

volatile status_code_t g_error_code = STATUS_CODE_OK;

extern volatile uint8_t cdc_rx_buf[64];
extern volatile uint8_t cdc_rx_len;

uint32_t wake_up_tick = 0;

bool first_boot = true;

extern PCD_HandleTypeDef hpcd_USB_FS;

/* USER CODE END PV */

void SystemClock_Config(void);
static void MX_GPIO_Init(void);
static void MX_DMA_Init(void);
static void MX_ADC1_Init(void);
static void MX_DAC1_Init(void);
static void MX_I2C2_Init(void);
static void MX_TIM2_Init(void);
static void MX_TIM6_Init(void);
static void MX_USART2_UART_Init(void);
static void MX_RTC_Init(void);
/* USER CODE BEGIN PFP */

void EnterStopMode(void);
void calculate_active_duration_ms(size_t bitstream_len);
void StartActiveWindowMs(uint32_t ms);
void make_bitstream_from_bytes(const uint8_t *data, size_t length);
void update_input_string(void);
int make_preamble(int start_idx);
void get_sineval_low(void);
void get_sineval_high(void);
void get_dc_mid(void);
uint32_t get_dac_sample_rate_hz(void);
static void RTC_SetWakeupTimer(uint32_t seconds);

static void start_audio_arm(void);
static void start_audio_trigger(void);
static void stop_audio_transmission(void);

void app_radio_test(void);

void read_buffer(void);

void process_transmission(uint8_t *transmission, int *dBm_value);

void create_payload_string(const char *user_string, int device_id,
                           const char *location, int8_t temperature,
                           rtc_time_t time_val, bool include_message_id,
                           int8_t message_id, int8_t rssi_dbm,
                           uint8_t *output_str, size_t output_str_size);

void create_string_from_received_data(const uint8_t *transmission, int rssi_dbm,
                                      uint8_t *output_str,
                                      size_t output_str_size);

static int init_luts_from_freqpair(void);

void Error_Handler_Code(status_code_t code);

void TryReceiveTimeSync(void);

/* USER CODE END PFP */

/**
 * @brief  The application entry point.
 * @retval int
 */
int main(void) {
  /* MCU Configuration--------------------------------------------------------*/

  /* Reset of all peripherals, Initializes the Flash interface and the Systick.
   */
  HAL_Init();

  /* Configure the system clock */
  SystemClock_Config();

  /* Initialize all configured peripherals */
  MX_GPIO_Init();
  MX_DMA_Init();
  MX_ADC1_Init();
  MX_DAC1_Init();
  MX_I2C2_Init();
  MX_TIM2_Init();
  MX_TIM6_Init();
  MX_USART2_UART_Init();
  MX_RTC_Init();
  MX_USB_Device_Init();
  /* USER CODE BEGIN 2 */

  if (OPERATION_MODE == 0) {
    LOGF("Starting in RX mode\r\n");
  } else if (OPERATION_MODE == 1) {
    LOGF("Starting in TX mode\r\n");
  } else {
    LOGF("Starting in Standalone mode\r\n");
  }

  if (OPERATION_MODE == 0 || OPERATION_MODE == 2) {
    DAC_SetMidlevel(&hdac1, 2048);
  }

  LOGF("\r\n");
  LOGF("UART boot OK\r\n");
  HAL_Delay(200);

  /* USER CODE END 2 */

  /* Infinite loop */
  /* USER CODE BEGIN WHILE */

  if (!FlashFlag_TimeWasSet()) {
    TryReceiveTimeSync();

    FlashFlag_SetTimeWasSet();
  }

  DS3231_PowerOn();
  DS3231_GetTime(&now);
  DS3231_ReadTemperature(&temp_int);
  DS3231_PowerOff();

  LOGF("Current RTC time: %02d:%02d:%02d, %02d/%02d/%04d, DOW: %u\r\n",
       now.hours, now.minutes, now.seconds, now.date, now.month,
       now.year + 2000, now.day);
  LOGF("Temperature: %d°C\r\n", temp_int);

  LOGF("-------------------------\r\n");
  LOGF("\r\n");

  if (OPERATION_MODE != 0) {
    WakeUp_Init(now);
  } else {
    LOGF("RX mode - skipping wakeup timer configuration\r\n");
  }

  Battery_IsLow(&hadc1);

  uint32_t dac_sample_rate = get_dac_sample_rate_hz();
  LOGF("DAC sample rate: %lu Hz\r\n", (unsigned long)dac_sample_rate);
  LOGF("\r\n");

  if (OPERATION_MODE != 1) {
    freq_pair = FreqConfig_FindFreqPair(dac_sample_rate);

    LOGF("Frequency pair: lower=%u Hz, higher=%u Hz\r\n",
         (unsigned int)freq_pair.lower_freq,
         (unsigned int)freq_pair.higher_freq);
    LOGF("--------------------------\r\n");
    LOGF("\r\n");
  } else {
    LOGF("Skipping finding frequencies\r\n");
  }

  if (OPERATION_MODE != 1) {
    if (init_luts_from_freqpair() != 0) {
      LOGF("LUT alloc failed\r\n");
      LOGF("--------------------------\r\n");
      Error_Handler_Code(STATUS_CODE_LUT_ALLOC_FAIL);
    }

    get_sineval_low();
    get_sineval_high();
    get_dc_mid();
  } else {
    LOGF("Skipping LUT preparation \r\n");
  }

  if (OPERATION_MODE != 2) {
    HAL_Delay(20);
    int8_t init_result = Radio_Init(OPERATION_MODE);
    if (init_result != 0) {
      LOGF("Failed to initialize radio in %s mode, error code: %d\r\n",
           OPERATION_MODE == 0 ? "RX" : "TX", init_result);
      LOGF("--------------------------\r\n");
      LOGF("\r\n");
      Error_Handler_Code(init_result);
    }

    uint8_t timeout = 100; // 100ms max
    while (timeout--) {
      uint8_t xosc_val = 0;
      uint8_t status = 0;
      CC1101_ReadReg(0x24, &xosc_val, &status);

      if (xosc_val & 0x01) { // XOSC_STABLE bit
        break;
      }
      HAL_Delay(1);
    }

    if (timeout == 0) {
      printf("ERROR: XOSC failed to stabilize\n");
    } else {
      printf("XOSC stabilized\n");
    }
    HAL_Delay(10);
  } else {
    LOGF("No radio in standalone mode - skipping radio initialization\r\n");

    // Power down CC1101 since we don't use it in standalone
    HAL_Delay(20);
    CC1101_PowerUpReset();
    HAL_Delay(10);
    Radio_EnterSleep();
    LOGF("CC1101 powered down for standalone mode\r\n");
  }

  LED_BlinkStatusCode(STATUS_CODE_OK);

  Relay_SetBypassMode();
  if (OPERATION_MODE != 0) {
    LOGF("Setting first alarm for TX and Standalone mode\r\n");
    RTC_SetWakeupTimer(1);
  }

  LOGF("\r\n");
  LOGF("Entering main loop...\r\n");
  LOGF("\r\n");

  int32_t wait_ms = 0;

  while (1) {
    LOGF("Entering STOP mode...\r\n");
    EnterStopMode();
    wake_up_tick = HAL_GetTick();
    DS3231_PowerOn();

    // 55s ensures at least one wakeup per minute to check the schedule window,
    // even if the exact-minute timer fires slightly early or late
    if (OPERATION_MODE != 0) {
      uint32_t sleep_seconds = 55;
      RTC_SetWakeupTimer(sleep_seconds);
    }

    Battery_IsLow(&hadc1);

    DS3231_GetTime(&now);
    DS3231_ReadTemperature(&temp_int);

    if (OPERATION_MODE != 0) {
      if (!WakeUp_CheckCurrentMinute(now)) {
        LOGF("Took %lu ms to check wakeup time\r\n",
             (unsigned long)(HAL_GetTick() - wake_up_tick));
        LOGF("Not in active window, going back to sleep...\r\n");
        DS3231_PowerOff();
        continue;
      }
    }

    if (OPERATION_MODE == 0) {
      LOGF("Woke up for RX reception\r\n");
      DS3231_PowerOn();

      if (USE_CABLE_TRANSMISSION) {
        Opamps_Enable(&hdac1);
        Relay_SetMixingMode();
      } else {
        Speaker_TurnOn();
      }

      int rx_len = Radio_Receive(transmission, sizeof(transmission));
      if (rx_len <= 4 || memchr(transmission, '/', rx_len) == NULL) {
        LOGF(
            "Failed to receive valid transmission, going back to sleep...\r\n");
        DS3231_PowerOff();
        Radio_EnterWOR();
        continue;
      }

      process_transmission(transmission, &dBm_value);

      DS3231_GetTime(&now);
      DS3231_ReadTemperature(&temp_int);
      DS3231_PowerOff();

      uint8_t output_str[256] = {0};
      create_string_from_received_data(transmission, dBm_value, output_str,
                                       sizeof(output_str));

      size_t payload_len = strlen((char *)output_str);

      if (USE_REED_SOLOMON_ERROR_CORRECTION) {
        uint8_t codeword[payload_len + RS_ERROR_CORRECTION_SYMBOLS];
        memset(codeword, 0, sizeof(codeword));
        RS_EncodeMsg((const uint8_t *)output_str, (int)payload_len, codeword,
                     RS_ERROR_CORRECTION_SYMBOLS);
        size_t codeword_len = payload_len + RS_ERROR_CORRECTION_SYMBOLS;
        if (codeword_len > sizeof(output_str)) {
          codeword_len = sizeof(output_str);
        }
        memcpy(output_str, codeword, codeword_len);
        payload_len = codeword_len;
      }

      make_bitstream_from_bytes(output_str, payload_len);

      calculate_active_duration_ms(BITSTREAM_LENGTH);
      uint32_t total_ms = (uint32_t)(total_time * 1000.0f);

      start_audio_arm();

      uint32_t target_tick = wake_up_tick + SYNC_DELAY_MS;
      wait_ms = (int32_t)(target_tick - HAL_GetTick());
      if (wait_ms > 1) {
        HAL_Delay((uint32_t)(wait_ms - 1));
      }
      while (__HAL_UART_GET_FLAG(&huart2, UART_FLAG_TC) == RESET)
        ;
      __HAL_UART_DISABLE(&huart2);
      while (HAL_GetTick() < target_tick)
        ;
      (void)SysTick->CTRL; // clear COUNTFLAG by reading it
      // Align to next SysTick reload for sub-ms trigger precision
      while ((SysTick->CTRL & SysTick_CTRL_COUNTFLAG_Msk) == 0)
        ;

      start_audio_trigger();
      __HAL_UART_ENABLE(&huart2);

      StartActiveWindowMs((uint32_t)(total_ms));

      uint32_t last_toggle = HAL_GetTick();
      while (!active_done) {
        uint32_t now_tick = HAL_GetTick();
        if ((now_tick - last_toggle) >= 100) { // blink every 100 ms
          last_toggle = now_tick;
          LED_Toggle();
        }
        __WFI(); // CPU sleeps while DMA+TIM2+DAC run
      }
      active_done = 0;
      HAL_GPIO_WritePin(LED_GPIO_Port, LED_Pin, GPIO_PIN_RESET);

      stop_audio_transmission();
      Radio_EnterWOR();

    } else if (OPERATION_MODE == 1) {
      LOGF("Woke up for TX transmission\r\n");
      Radio_EnterIdle();

      LOGF("Starting transmission over radio...\r\n");
      Relay_SetMixingMode(); // click marks TX start for offline analysis

      LED_ON();

      uint32_t radio_tx_start = HAL_GetTick();
      Radio_Transmit();
      uint32_t radio_tx_end = HAL_GetTick();

      LOGF("Radio transmission took %lu ms\r\n",
           (unsigned long)(radio_tx_end - radio_tx_start));
      Relay_SetBypassMode();
      LED_OFF();

      Radio_EnterSleep();
    } else {
      LOGF("Woke up for Standalone mode\r\n");
      DS3231_PowerOn();

      if (USE_CABLE_TRANSMISSION) {
        Opamps_Enable(&hdac1);
        Relay_SetMixingMode();
      } else {
        Speaker_TurnOn();
      }

      DS3231_GetTime(&now);
      DS3231_ReadTemperature(&temp_int);
      DS3231_PowerOff();

      uint8_t output_str[256] = {0};
      create_payload_string(INCLUDE_USER_STRING ? USER_STRING : NULL,
                            INCLUDE_DEVICE_ID ? DEVICE_ID : -1,
                            INCLUDE_LOCATION ? LOCATION : NULL,
                            INCLUDE_TEMPERATURE ? temp_int : -1, now, false, -1,
                            0, output_str, sizeof(output_str));

      size_t payload_len = strlen((char *)output_str);

      if (USE_REED_SOLOMON_ERROR_CORRECTION) {
        uint8_t codeword[payload_len + RS_ERROR_CORRECTION_SYMBOLS];
        memset(codeword, 0, sizeof(codeword));
        RS_EncodeMsg((const uint8_t *)output_str, (int)payload_len, codeword,
                     RS_ERROR_CORRECTION_SYMBOLS);
        size_t codeword_len = payload_len + RS_ERROR_CORRECTION_SYMBOLS;
        if (codeword_len > sizeof(output_str)) {
          codeword_len = sizeof(output_str);
        }
        memcpy(output_str, codeword, codeword_len);
        payload_len = codeword_len;
      }

      make_bitstream_from_bytes(output_str, payload_len);

      calculate_active_duration_ms(BITSTREAM_LENGTH);
      uint32_t total_ms = (uint32_t)(total_time * 1000.0f);

      start_audio_arm();

      uint32_t target_tick = wake_up_tick + SYNC_DELAY_MS;
      wait_ms = (int32_t)(target_tick - HAL_GetTick());
      if (wait_ms > 1) {
        HAL_Delay((uint32_t)(wait_ms - 1));
      }
      while (__HAL_UART_GET_FLAG(&huart2, UART_FLAG_TC) == RESET)
        ;
      __HAL_UART_DISABLE(&huart2);
      while (HAL_GetTick() < target_tick)
        ;
      (void)SysTick->CTRL; // clear COUNTFLAG by reading it
      // Align to next SysTick reload for sub-ms trigger precision
      while ((SysTick->CTRL & SysTick_CTRL_COUNTFLAG_Msk) == 0)
        ;

      start_audio_trigger();

      StartActiveWindowMs((uint32_t)(total_ms));

      uint32_t last_toggle = HAL_GetTick();
      uint32_t now = 0;
      while (!active_done) {
        now = HAL_GetTick();
        if ((now - last_toggle) >= 100) { // blink every 100 ms
          last_toggle = now;
          LED_Toggle();
        }
        __WFI(); // CPU sleeps while DMA+TIM2+DAC run
      }
      active_done = 0;
      HAL_GPIO_WritePin(LED_GPIO_Port, LED_Pin, GPIO_PIN_RESET);

      stop_audio_transmission();
    }

    /* USER CODE END WHILE */

    /* USER CODE BEGIN 3 */
  }
  /* USER CODE END 3 */
}

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
/* USER CODE BEGIN 4 */

void EnterStopMode(void) {
  __HAL_GPIO_EXTI_CLEAR_IT(GPIO_PIN_7);
  HAL_NVIC_ClearPendingIRQ(EXTI9_5_IRQn);
  __HAL_RTC_WAKEUPTIMER_CLEAR_FLAG(&hrtc, RTC_FLAG_WUTF);
  PWR->SCR = PWR_SCR_CWUF;

  DBGMCU->CR &=
      ~(DBGMCU_CR_DBG_STOP | DBGMCU_CR_DBG_SLEEP | DBGMCU_CR_DBG_STANDBY);

  if (OPERATION_MODE == 0) {
    HAL_RTCEx_DeactivateWakeUpTimer(&hrtc);
    HAL_NVIC_EnableIRQ(EXTI9_5_IRQn);
  } else {
    HAL_NVIC_DisableIRQ(EXTI9_5_IRQn);
    HAL_NVIC_EnableIRQ(RTC_WKUP_IRQn);
  }

  __DSB();
  __ISB();
  HAL_SuspendTick();
  HAL_PWREx_EnterSTOP1Mode(PWR_STOPENTRY_WFI);

  SystemClock_Config();
  HAL_ResumeTick();
  HAL_GPIO_WritePin(GPIOA, GPIO_PIN_15, GPIO_PIN_SET);
  MX_I2C2_Init();
  MX_USART2_UART_Init();
  __HAL_UART_ENABLE(&huart2);

  HAL_Delay(10);
  HAL_GPIO_WritePin(GPIOA, GPIO_PIN_15, GPIO_PIN_RESET);
  wake_up_tick = HAL_GetTick();

  // RX only: wait for GDO0 to deassert after wakeup
  if (OPERATION_MODE == 0) {
    uint32_t settle = HAL_GetTick();
    while (HAL_GPIO_ReadPin(GPIOB, GPIO_PIN_7) == GPIO_PIN_RESET &&
           HAL_GetTick() - settle < 5) {
    }
  }

  HAL_NVIC_EnableIRQ(EXTI9_5_IRQn);
  if (OPERATION_MODE == 0) {
    __HAL_GPIO_EXTI_CLEAR_IT(GPIO_PIN_7);
    HAL_NVIC_ClearPendingIRQ(EXTI9_5_IRQn);
  } else {
    __HAL_RTC_WAKEUPTIMER_CLEAR_FLAG(&hrtc, RTC_FLAG_WUTF);
  }
  __HAL_PWR_CLEAR_FLAG(PWR_FLAG_WU);
  PWR->SCR = PWR_SCR_CWUF;
}

void StartActiveWindowMs(uint32_t ms) {
  active_done = 0;

  if (ms == 0) {
    ms = 1;
  }

  HAL_TIM_Base_Stop_IT(&htim6);
  __HAL_TIM_SET_COUNTER(&htim6, 0);
  __HAL_TIM_SET_AUTORELOAD(&htim6, ms - 1);

  __HAL_TIM_CLEAR_FLAG(&htim6, TIM_FLAG_UPDATE);
  __HAL_TIM_CLEAR_IT(&htim6, TIM_IT_UPDATE);

  HAL_TIM_Base_Start_IT(&htim6);
}

void HAL_TIM_PeriodElapsedCallback(TIM_HandleTypeDef *htim) {
  if (htim->Instance == TIM6) {
    HAL_TIM_Base_Stop_IT(&htim6); // <- makes it one-shot reliably
    active_done = 1;
  }
}

int make_preamble(int start_idx) {
  int k = start_idx;
  uint16_t id = 0x2DD4;
  for (int i = 0; i < 16 && k < BITSTREAM_LENGTH; ++i) {
    bitstream[k++] = (((id >> (15 - i)) & 1) ^ BIT_POLARITY);
  }

  return k;
}
void make_bitstream_from_bytes(const uint8_t *data, size_t length) {
  size_t k = 0;

  if (k < BITSTREAM_LENGTH) {
    bitstream[k++] = 2; // silence
  }

  for (size_t i = 0; i < length && k < BITSTREAM_LENGTH; ++i) {
    for (int b = 7; b >= 0 && k < BITSTREAM_LENGTH; --b) {
      bitstream[k++] = (uint8_t)(((data[i] >> b) & 1u) ^ BIT_POLARITY);
    }
  }

  for (int i = 0; i < 8 && k < BITSTREAM_LENGTH; ++i) {
    bitstream[k++] = 2; // silence
  }

  while (k < BITSTREAM_LENGTH) {
    bitstream[k++] = 2; // silence
  }
}

void update_input_string(void) {
  input_string[0] = '\0';
  size_t offset = 0;
  size_t remaining = MAX_NUM_CHARS;
  int n = 0;

  if (INCLUDE_USER_STRING) {
    n = snprintf(&input_string[offset], remaining, "/STR%s", USER_STRING);
    if (n > 0 && (size_t)n < remaining) {
      offset += (size_t)n;
      remaining -= (size_t)n;
    }
  }
  if (INCLUDE_DEVICE_ID) {
    n = snprintf(&input_string[offset], remaining, "%s/DID%d",
                 (offset > 0) ? "" : "", DEVICE_ID);
    if (n > 0 && (size_t)n < remaining) {
      offset += (size_t)n;
      remaining -= (size_t)n;
    }
  }
  if (INCLUDE_LOCATION) {
    n = snprintf(&input_string[offset], remaining, "%s/LOC%s",
                 (offset > 0) ? "" : "", LOCATION);
    if (n > 0 && (size_t)n < remaining) {
      offset += (size_t)n;
      remaining -= (size_t)n;
    }
  }
  if (INCLUDE_TEMPERATURE) {
    n = snprintf(&input_string[offset], remaining, "%s/TMP%d",
                 (offset > 0) ? "" : "", temp_int);
    if (n > 0 && (size_t)n < remaining) {
      offset += (size_t)n;
      remaining -= (size_t)n;
    }
  }
  if (INCLUDE_TIME) {
    n = snprintf(&input_string[offset], remaining,
                 "%s/TIM%02d%02d%02d%02d%02d%02d%04d", (offset > 0) ? "" : "",
                 now.hours, now.minutes, now.seconds, now.day, now.date,
                 now.month, now.year);

    if (n > 0 && (size_t)n < remaining) {
      offset += (size_t)n;
      remaining -= (size_t)n;
    }
  }
  if (strlen(input_string) > 0) {
    n = snprintf(&input_string[offset], remaining, "/");
    if (n > 0 && (size_t)n < remaining) {
      offset += (size_t)n;
      remaining -= (size_t)n;
    }
  }
}

void get_sineval_low(void) {
  const float dac_max = 4095.0f;
  const float dac_mid = dac_max / 2.0f;
  const float amplitude = (1.5f / 1.65f) * (SIGNAL_ATTENUATION / 100.0f);

  for (uint16_t i = 0; i < freq_pair.lower_freq_samples; i++) {
    sine_val_low[i] =
        (uint32_t)(dac_mid *
                   (1.0 + sinf(2.0 * pi * i / freq_pair.lower_freq_samples) *
                              amplitude));
  }
}

void get_sineval_high(void) {
  const float dac_max = 4095.0f;
  const float dac_mid = dac_max / 2.0f;
  const float amplitude = (1.5f / 1.65f) * (SIGNAL_ATTENUATION / 100.0f);

  for (uint16_t i = 0; i < freq_pair.higher_freq_samples; i++) {
    sine_val_high[i] =
        (uint32_t)(dac_mid *
                   (1.0 + sinf(2.0 * pi * i / freq_pair.higher_freq_samples) *
                              amplitude));
  }
}

void get_dc_mid(void) {
  uint32_t mid_value = (uint32_t)(4095.0 / 2.0);
  for (uint16_t i = 0; i < freq_pair.lower_freq_samples; i++) {
    dc_mid[i] = mid_value;
  }
}

uint32_t get_dac_sample_rate_hz(void) {
  uint32_t tim_clk = HAL_RCC_GetPCLK1Freq();
  if ((RCC->CFGR & RCC_CFGR_PPRE1) != RCC_CFGR_PPRE1_DIV1)
    tim_clk *= 2; // timer clock doubled if APB prescaler != 1

  return tim_clk / ((htim2.Init.Prescaler + 1) * (htim2.Init.Period + 1));
}
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

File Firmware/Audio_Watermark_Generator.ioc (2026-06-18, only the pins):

Mcu.UserName=STM32G431KBTx
PA0.Signal=ADC1_IN1
PA1.Signal=GPIO_Output
PA10.Signal=GPIO_Output
PA11.Signal=USB_DM
PA12.Signal=USB_DP
PA13.Signal=SYS_JTMS-SWDIO
PA14.Signal=SYS_JTCK-SWCLK
PA15.Signal=GPIO_Output
PA2.Signal=USART2_TX
PA3.Signal=USART2_RX
PA4.Signal=COMP_DAC11_group
PA5.Signal=GPIO_Output
PA6.Signal=GPIO_Output
PA7.Signal=GPIO_Output
PA8.Signal=I2C2_SDA
PA9.Signal=I2C2_SCL
PB0.Signal=GPIO_Output
PB3.Signal=GPIO_Output
PB4.Signal=GPIO_Output
PB5.Signal=GPIO_Input
PB6.Signal=GPIO_Output
PB7.Signal=GPXTI7
PF0-OSC_IN.Signal=RCC_OSC_IN
PF1-OSC_OUT.Signal=RCC_OSC_OUT

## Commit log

2025-09-04 Init commit
    [burst_with_markers_1.csv, burst_with_markers_10.csv, burst_with_markers_11.csv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]
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2025-09-16 Fixed splash by using a buffer
    [STM_TESTING.ioc, main.c]
2025-09-16 Enhance DAC callback functions to manage buffer filling and current period updates
2025-09-17 Refactor battery configuration parameters in STM_TESTING.ioc and update function prototype comment in main.c
2025-09-18 Refactor DAC handling and timer configuration for improved pulse timing and reset functionality
    [main.c]
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2025-09-23 Fix silence duration calculation and clean up comments in main.c
    [main.c]
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2025-09-25 Update CI workflow to trigger on push to main (#22)
    * Update CI workflow to trigger on push to main
    Add push event trigger for main branch
    * Add firmware output verification step
    Added checks to ensure firmware outputs are produced after the build step.
    * Update GitHub Actions workflow for STM32 CI
    * Update workflow to trigger on push to main
    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
2025-09-26 18 rtc (#21)
    * Add DS3231 RTC driver implementation with read and set time functions
    * Update STM32 project configuration to include I2C support and add DS3231 driver files
    * Enable I2C module and add MSP initialization and de-initialization functions for I2C1
    * Update user configuration to disable location and temperature inclusion in watermark
    * Add I2C1 initialization and integrate DS3231 RTC time setting and reading
    * Add extra_sources.cmake to manage user-defined source files and includes
    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
2025-09-26 Decoder (#19)
    * Beginning of frequency analysis in python
    * Add signal_out_3.wav audio file
    * Prototupe decoder using goertzel
    * print encoded message with goertzel
    * test with finding preamble with cross correlation
    * add separate .py file for preamble generation in .wav demodulator uses .wav directly
    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
    [frequency_segments.csv, test_values.csv, test_values2.csv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]
2025-09-29 Refactor demodulator.py for improved readability and maintainability;… (#24)
    * Refactor demodulator.py for improved readability and maintainability; adjust formatting, enhance function definitions, and add message printing logic.
    * Update user_config.h to set initial RTC time and enable watermark values
2025-09-29 15 test if pulse width is correct and sends complete message (#25)
    * Remove csv files as it is no longer needed in the project
    * Update MAX_NUM_CHARS to 115, add termination sign in update_input_string, and adjust total_time calculation for safety margin
    * Update wav_path in spectogram.py and comment out optional debug plots for clarity
    * Enhance message validation in print_message function to handle empty messages and missing preamble/termination warnings
    * Update RTC initial configuration to set time to 11:01:00 and disable initial time setting
    [burst_with_markers_1.csv, burst_with_markers_10.csv, burst_with_markers_11.csv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]
2025-10-01 29 implement clock with battery (#30)
    * Fix formatting and add missing return statements in ds3231.c
    * Add DS3231 power control functions and update GPIO initialization
    * Update GPIO settings and adjust peripheral configurations in STM_TESTING.ioc
    * Add time tracking for decoded messages and clean up input filename
    * Update spectrogram visualization: restore plotting functionality and change wav file path
    [STM_TESTING.ioc, ds3231.c, main.c]
2025-10-02 Toggle delay (#33)
    * Add Python GUI directories to .gitignore
    * Update .gitignore to include .DS_Store
    * Add STM32 build and flash tool GUI implementation
    * Add setup script for ARM GNU Toolchain installation
    * Add ENABLE_DELAYED_START configuration and update callback logic
    * Rename ioc file
    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
2025-10-06 26 message storage (#34)
    * Update .gitignore to include all .wav files
    * Update .gitignore to ignore all .DS_Store files
    * Remove duplicate entry for .DS_Store
    * Enhance print_message function to log errors and decoded messages to output file; improve seconds_to_hms for better time formatting
    * Update output filename to match input filename extension
    ---------
2025-10-08 Add GUI for FSK demodulator with preset options and threading support (#38)
2025-10-08 Refactor print_message function to include labels output and improve error handling (#47)
2025-10-09 Gui (#41)
    * Enhance STM32 build and flash tool with dynamic path resolution, improved user configuration handling, and added logging features
    * Add icon files for Python GUI implementation
    * Refactor STM32Tool.spec to use app_name variable for consistency and clarity
    * Refactor CMakeLists.txt for improved organization and clarity, including enhanced linker script handling and removal of unnecessary comments.
    * Update user configuration for RTC initialization and watermark settings
    * Add waveform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
2025-10-13 44 demodulator gui as app (#56)
    * Add initial Demodulator.spec configuration for GUI application
    * Enhance FSK demodulator: update print_message function signature, add message segmentation, and improve GUI with new options for readable output and segmentation controls.
    * Add GUI for FSK demodulator with presets and segmentation options; update .spec for icon support
    * Remove Goertzel demodulator implementation from Python module
    * Update main.yml (#49)
    * Gui (#41)
    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
2025-11-04 Fixed gui (#61)
    * Refactor GUI layout and enhance build process logging
    * Update FSK frequency pair configuration and adjust corresponding sample definitions
    [build.py, user_config.py]
2025-11-04 Refactor message printing logic in print_message function for clarity and efficiency (#62)
2025-11-24 58 gpio pins for relay swithing (#59)
    * Add ADC and USART initialization, and implement DWT delay functions
    * Refactor main.c: Remove USART2 initialization and clean up function definitions
    * Add ADC configuration and update MCU peripherals in project settings
    * Enable ADC module and implement MSP initialization and de-initialization functions for ADC1
    * Update STM32 driver sources: add ADC HAL files and remove DAC HAL files
    * Update project configuration: remove ADC1 settings and adjust MCU pin assignments
    * Remove ADC1 initialization and configuration code from main.c and HAL MSP files
    * Update STM32 driver sources: replace ADC HAL files with DAC HAL files
    * Remove unused audio pro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
    [Audio_Watermark_Generator.ioc, main.c]
2025-11-25 Gpio toggle for speaker (#63)
    * Refactor main function and related initialization functions for improved readability and consistency
    * Update GPIO pin configuration for improved functionality and organization
    * Update RTC initialization and GPIO configuration for speaker control
2025-11-28 67 toggle cable and speaker (#68)
    * Update transmission mode configuration and set FSK frequency pair to default
    * Adjust transmission logic for speaker and cable; update margin timing
    * Add transmission settings to GUI and update user config handling
    * Refactor sine wave generation functions and variable names for clarity
2025-12-03 Bug fix (#69)
    * Update user configuration and main logic for transmission methods and timing adjustments
    * Fix GPIO pin assignments for cable transmission in HAL_TIM_PeriodElapsedCallback and HAL_TIM_PWM_PulseFinishedCallback
    [main.c]
2025-12-03 Fix GPIO pin usage for cable transmission in PWM callback (#70)
    [main.c]
2025-12-09 Fix lenght (#72)
    * Refactor character length definitions and improve bitstream handling in main.c
    * Update user configuration: reset starting minute, adjust repeat interval, and modify user string
    * Update application name to "Audio Watermark Flash Tool" in STM32Tool.spec and GUI title
    * Update user configuration: enable default interval between repeats, reset user string, and enable speaker transmission
    [main.c]
2026-01-12 88 better selection of frequency pairs (#91)
    * Refactor FSK frequency configuration by removing frequency pair options and defining specific lower and higher frequencies
    * Refactor FSK processing by introducing dynamic sample and period calculations for lower and higher frequencies
2026-06-18 release: thesis submission — finalize system and documentation (#170)
    * 84 better sleep mode (#93)
    * Implement alarm functionality and GPIO interrupt for DS3231 RTC
    * Add .gitignore file to exclude build artifacts and temporary files
    * Init files for a new build
    * Update project configuration for improved GPIO and timer settings
    * Enhance sleep mode functionality and timer integration
    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
    [1049.stp, 18650.STEP, 533980271.step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]

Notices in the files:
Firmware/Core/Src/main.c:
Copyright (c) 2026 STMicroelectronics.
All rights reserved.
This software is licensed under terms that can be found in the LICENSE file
